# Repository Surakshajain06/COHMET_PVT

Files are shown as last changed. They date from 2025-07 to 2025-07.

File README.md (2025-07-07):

    

# **CMC COHMET**
## **Cognitive and Hand Motor Enhancement Trainer**

COHMET (Cognitive and Hand Motor Enhancement Trainer) is a smart, interactive pegboard designed to aid hand coordination and cognitive development—especially in stroke rehabilitation settings. It combines visual guidance through LED-lit wells, fixed-colored pegs, and real-time feedback to enhance user engagement. The system is Bluetooth-enabled, with app-based control for tracking progress, timing, and customizable audio prompts.

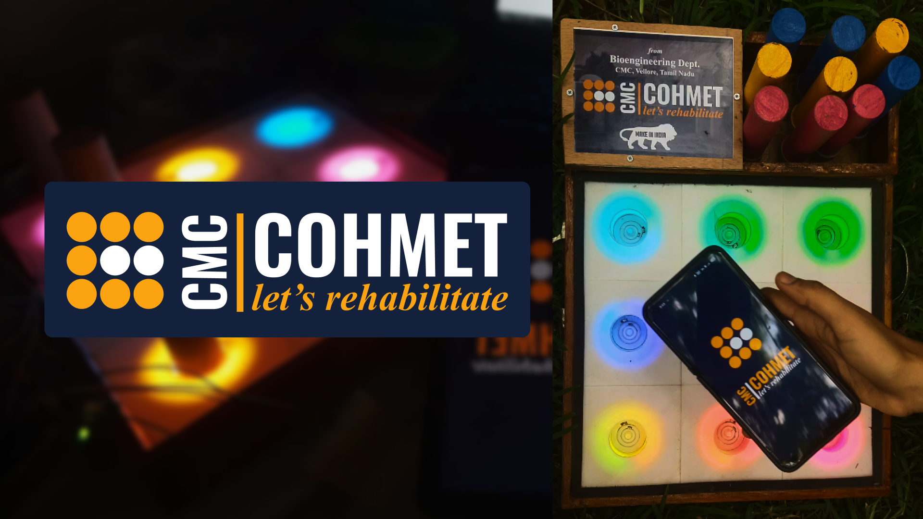
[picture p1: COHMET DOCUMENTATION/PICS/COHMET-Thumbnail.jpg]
Hero Image


## 🎯 **Functionality overview**
COHMET offers guided color-matching tasks that help improve motor skills and cognitive responses. Real-time peg placement detection ensures accurate activity tracking and user feedback. Designed with future expandability in mind, including data sync, remote monitoring, and multilingual support.

## 📱 **App integration and features**
A companion mobile app allows users or therapists to control sessions, monitor timing, and choose languages (English, Tamil, Hindi). Audio prompts, user tracking, and session customization are planned features under active development. COHMET is built to support scalable digital integration for remote therapy use.

## 📦 **Physical Design Overview**
COHMET features a compact wooden board with 9 wells and color-coded pegs, making it simple, durable, and user-friendly. Wells are illuminated for visual cues, and components are engineered for intuitive interaction. The system is lightweight and portable, suitable for clinics, therapy centers, or at-home use.

## ⚠️ Disclaimer
*COHMET is a prototype currently under development and intended for research and educational purposes only. Features, design, and performance are subject to change. The developers are not responsible for any misuse, damage, or injury resulting from the use of this system. Certain technical components and mechanisms are patent-pending and may not be reused or replicated without permission.*

## **ELECTRONICS STRUCTURE**
| Final Schematics | Final PCB |
| :---: | :---: |
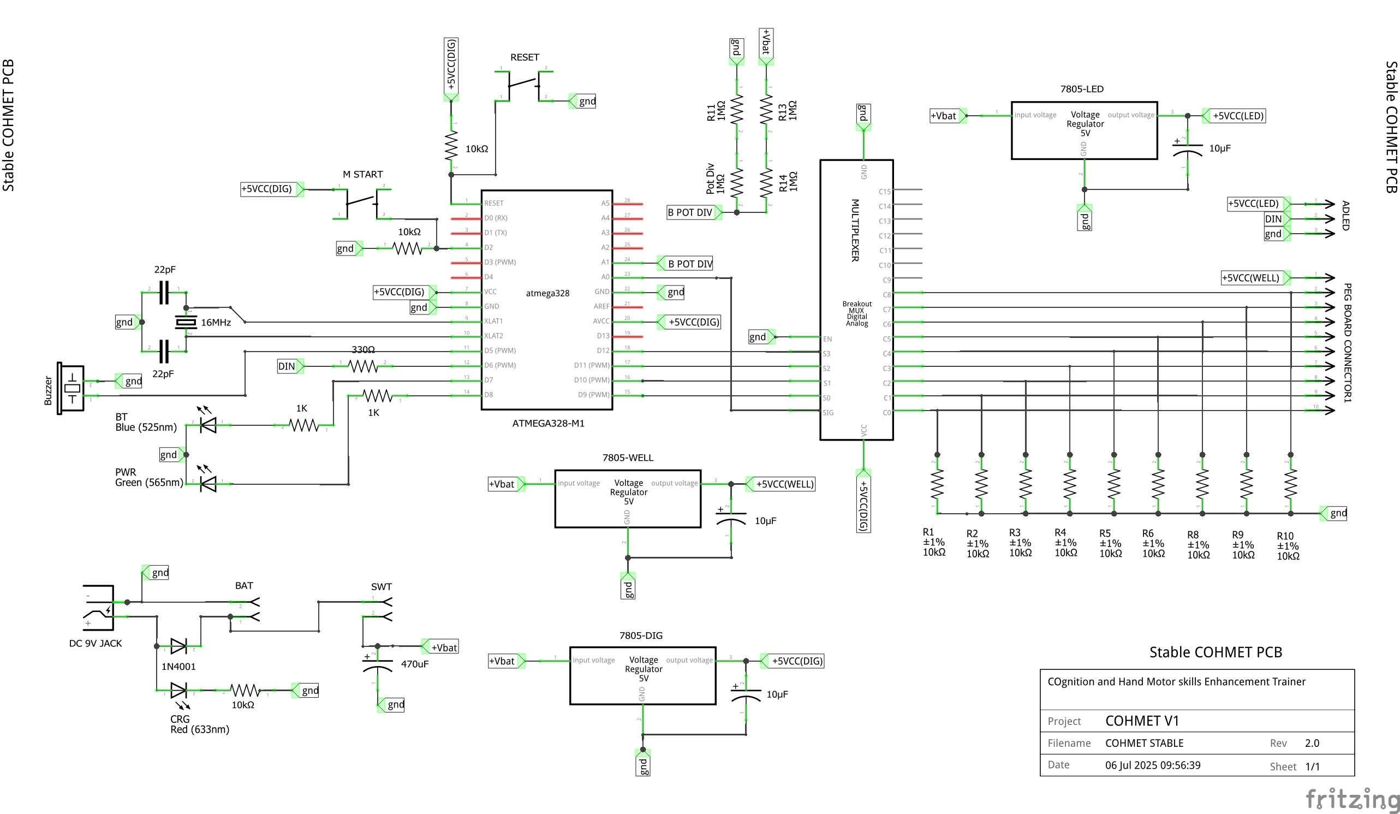
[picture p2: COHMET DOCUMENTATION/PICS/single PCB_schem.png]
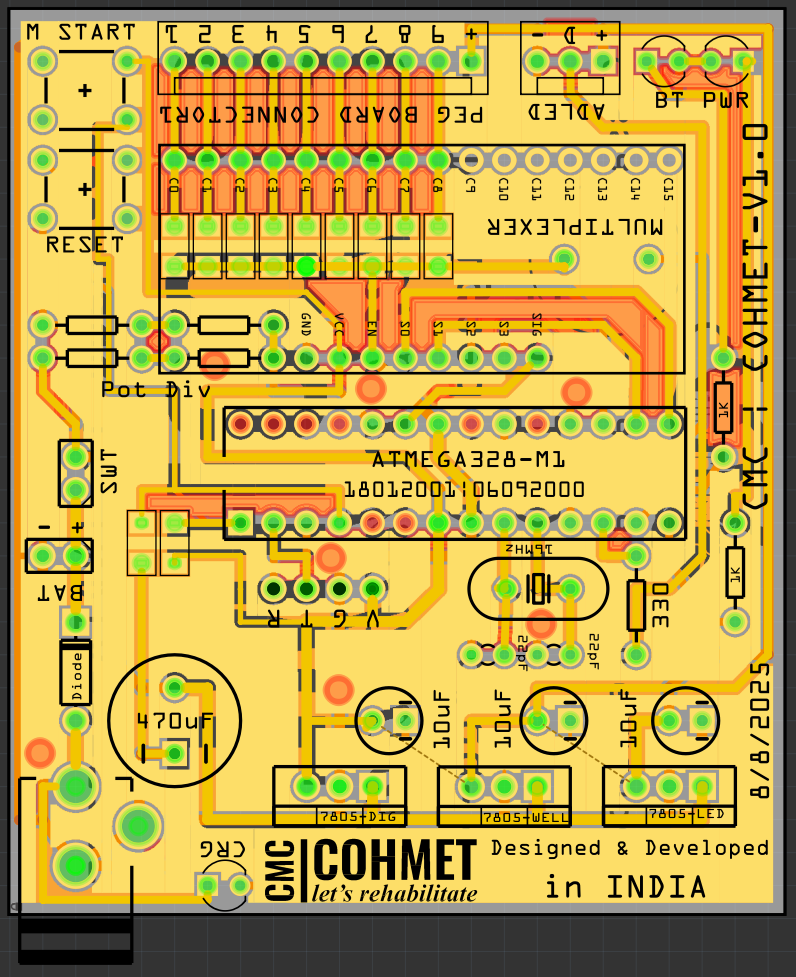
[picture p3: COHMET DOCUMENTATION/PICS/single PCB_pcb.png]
|  |  |

## **MECHANICAL STRUCTURE**
| Main Structures | Structural Assembly |
| :---: | :---: |
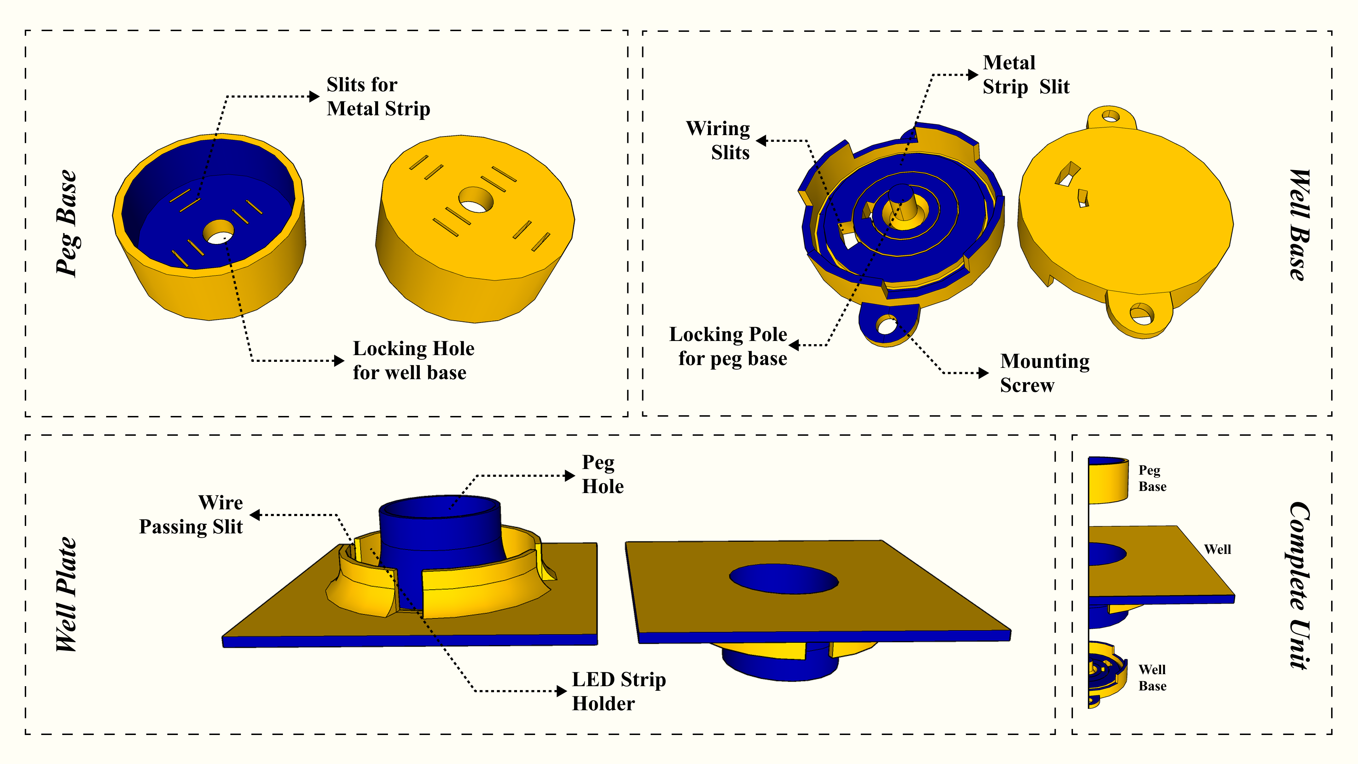
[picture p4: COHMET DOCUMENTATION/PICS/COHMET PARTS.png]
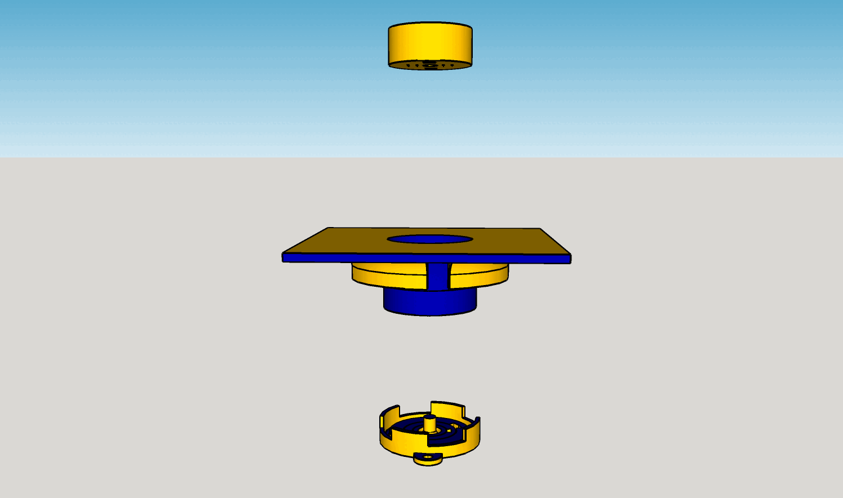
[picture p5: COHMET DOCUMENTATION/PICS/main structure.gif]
|  |  |

## **WEBSITE STRUCTURE**
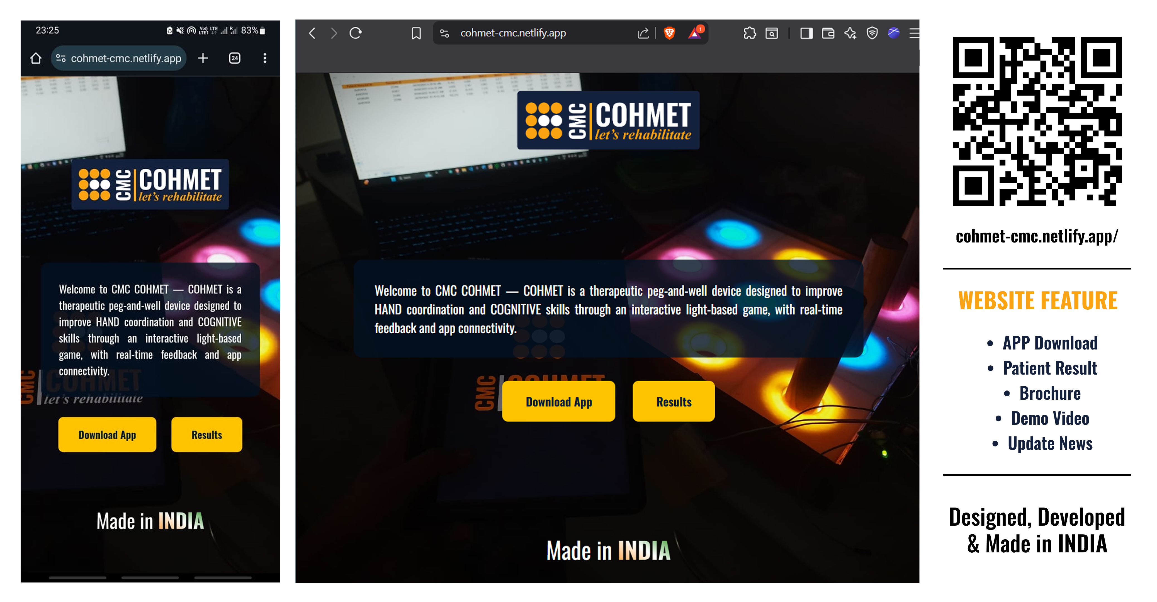
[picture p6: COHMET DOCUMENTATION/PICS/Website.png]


## **APP STRUCTURE**
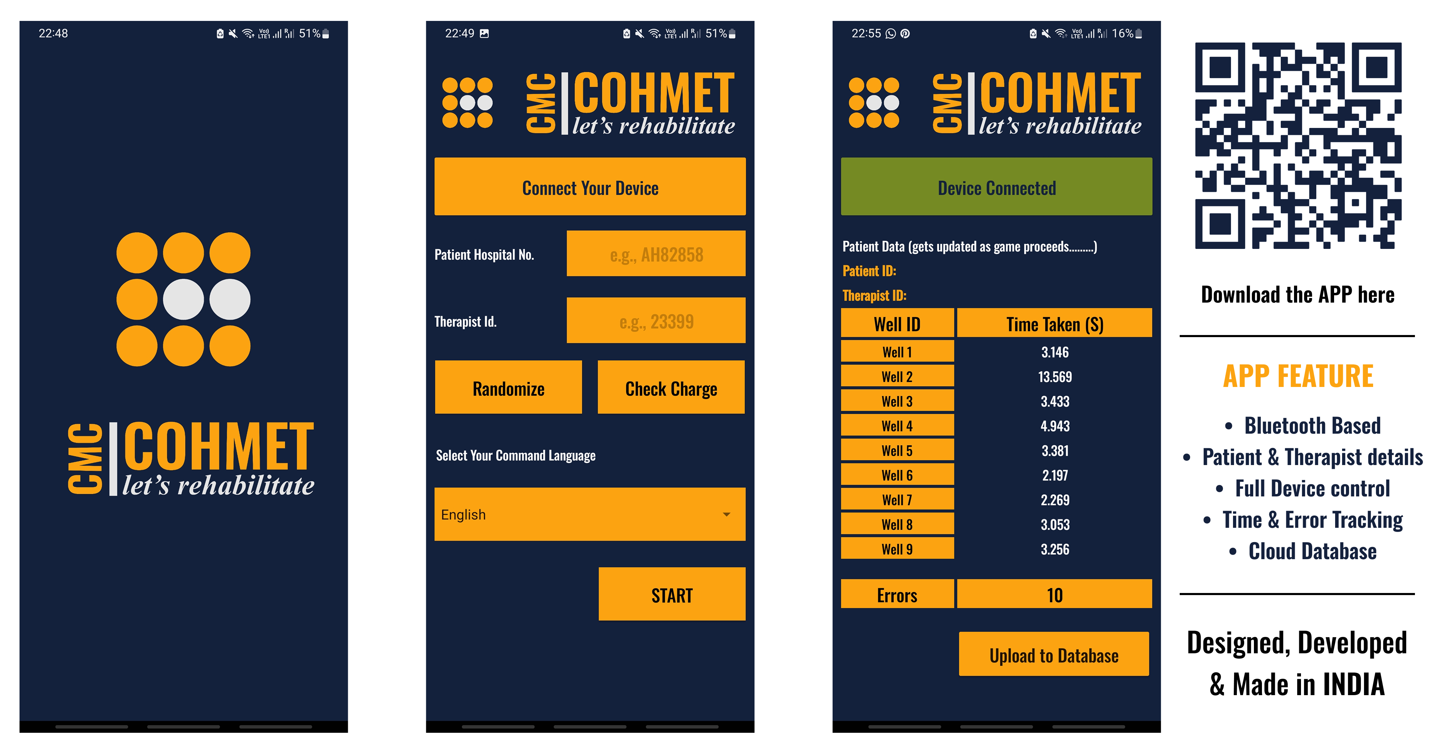
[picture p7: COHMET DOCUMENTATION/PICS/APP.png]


## 🔧 Future work
 
### 🔧 Proposed Improvements & Game Features

| **Category** | **Feature / Game Mode** | **Description** |
|---|---|---|
| ✅ **Hardware Optimization** | Minimize LED Voltage Regulator Heating | Improve power efficiency using low-dropout or switching regulators to reduce heat. |
| | Compact & Lightweight Design | Use smaller PCB, lighter enclosure, and optimized layout for portability. |
| | Cost Optimization | Use cost-effective components without reducing performance or safety. |
| 🔊 **Audio Functionality**  | Multilingual Audio Prompts (English, Tamil, Hindi) | Add voice instructions in three languages for accessibility. |
| | Custom Voice/Sound Support | Allow uploading custom audio files for personalized interaction. |
| ⏲️ **Training Flexibility** | Customizable Timer per Well | Set individual timing for each well to adapt training difficulty. |
| 🎮 **Game Modes** | **Memory Recall Game** | Flash a sequence of colors, and player replicates it using pegs. |
| | **Reaction Time Game** | Random fast-flashing wells; player responds quickly to correct one. |
| | **Color-Match Training (Current)** | Match colored peg with correct well; error shown with red flash. |
| | **Sequence Training Game** | Player must follow a specific color sequence given by audio or lights. |
| | **Timer Challenge Mode** | Complete all placements within a limited time. |
| | **Obstacle Mode** | Include false signals or distractions to improve focus and cognition. |
| | **Progressive Levels** | Increase difficulty with faster timing, more colors, and advanced logic. |
| 🧠 **Cognitive/Physical Goals** | Focus Training | Single-color attention game with distractions to improve sustained focus. |
| | Left-Right Alternation Game | Alternate peg placements to engage both hands and aid rehabilitation. |
| 📱 **User Control** | Mobile App-Based Control & Sync | Set modes and track results via Bluetooth-connected mobile app. |

## Behind the development



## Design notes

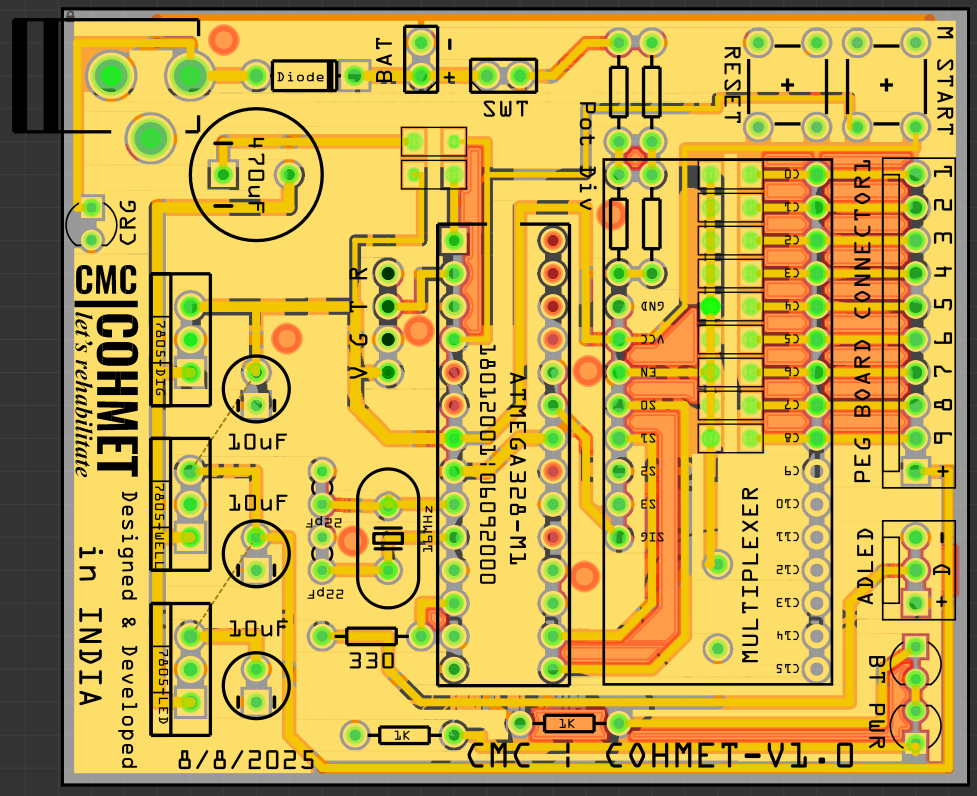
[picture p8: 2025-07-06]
COHMET ELECTRONICS/single PCB_pcb.png

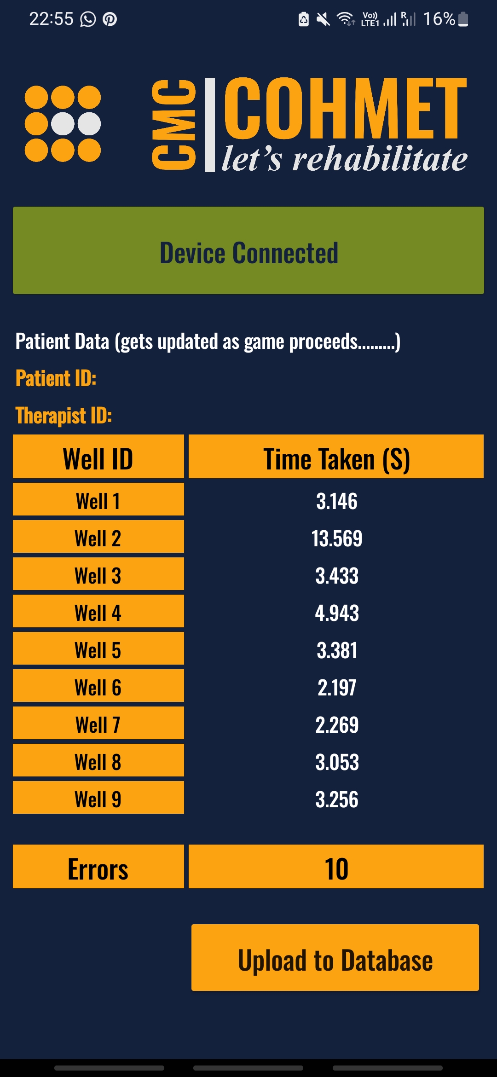
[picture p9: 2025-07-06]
COHMET DOCUMENTATION/PICS/APP4.jpg

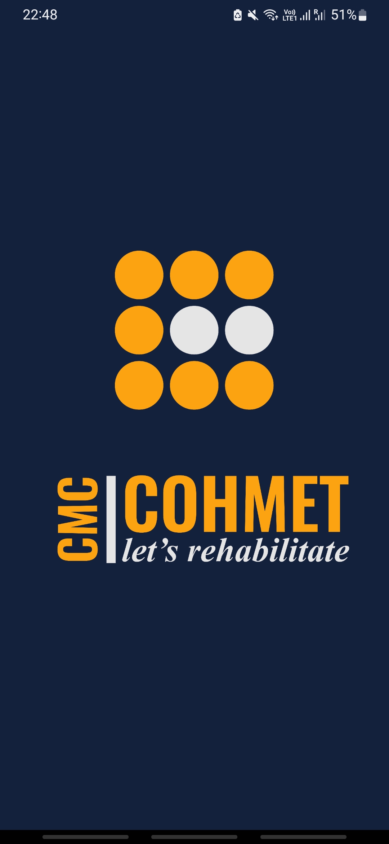
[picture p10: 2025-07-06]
COHMET DOCUMENTATION/PICS/APP1.jpg

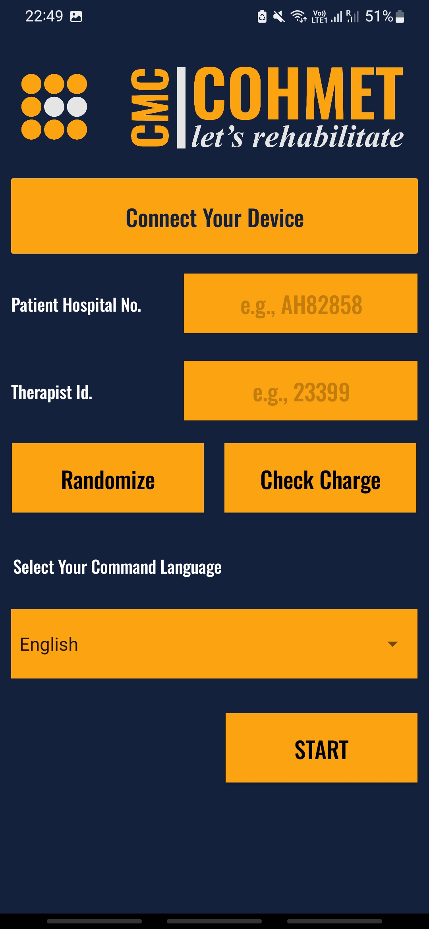
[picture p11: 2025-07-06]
COHMET DOCUMENTATION/PICS/APP2.jpg

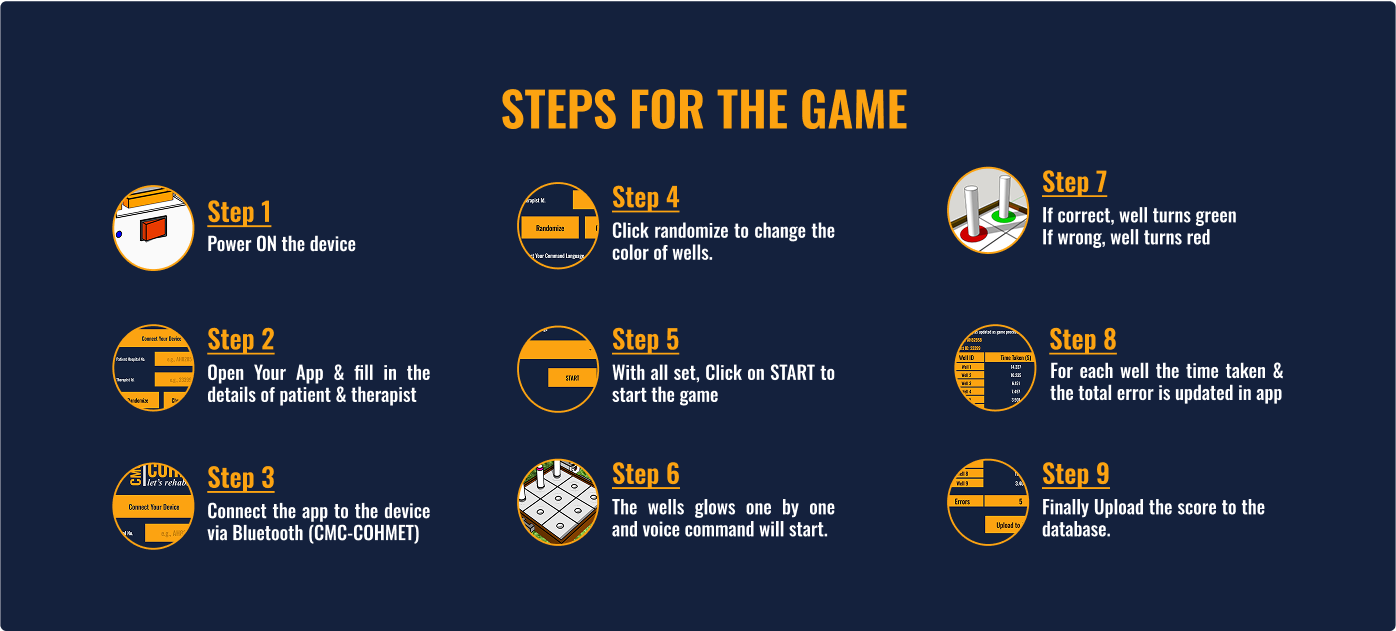
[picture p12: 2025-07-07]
COHMET WEBSITE/rules.png

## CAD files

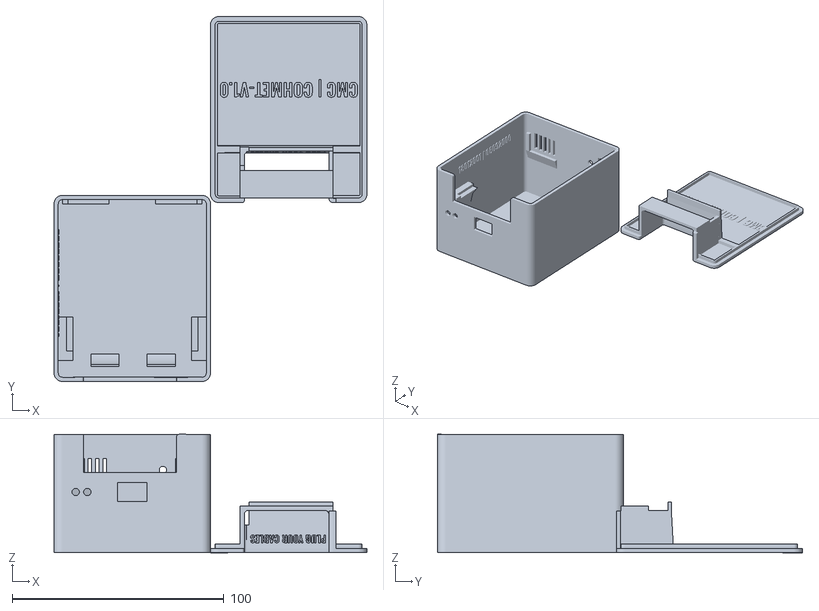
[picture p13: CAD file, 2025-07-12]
COHMET MECHNICAL/Prinatbles/ELECTRONICS CASE.stl
148.0 x 172.6 x 56.0

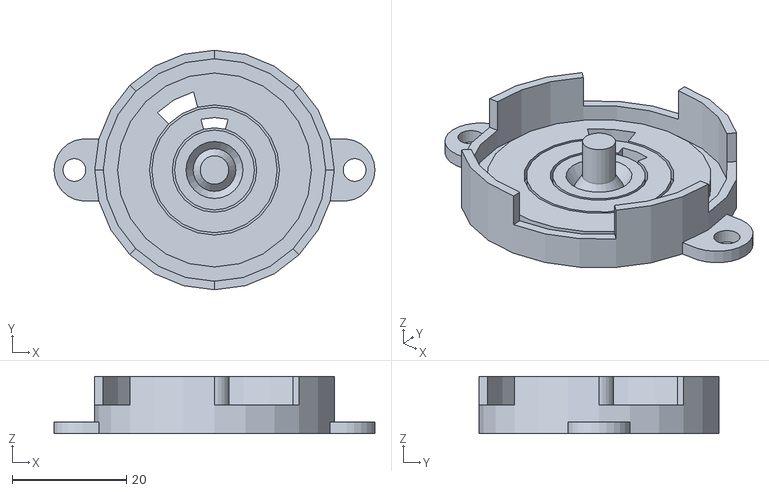
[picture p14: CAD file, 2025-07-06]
COHMET MECHNICAL/Prinatbles/Well Base.stl
56.3 x 42.0 x 10.0

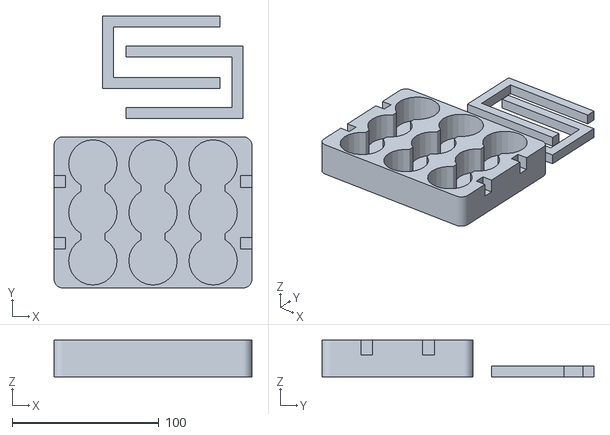
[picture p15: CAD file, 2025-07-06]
COHMET MECHNICAL/Prinatbles/Peg tray.stl
135.0 x 185.4 x 25.0

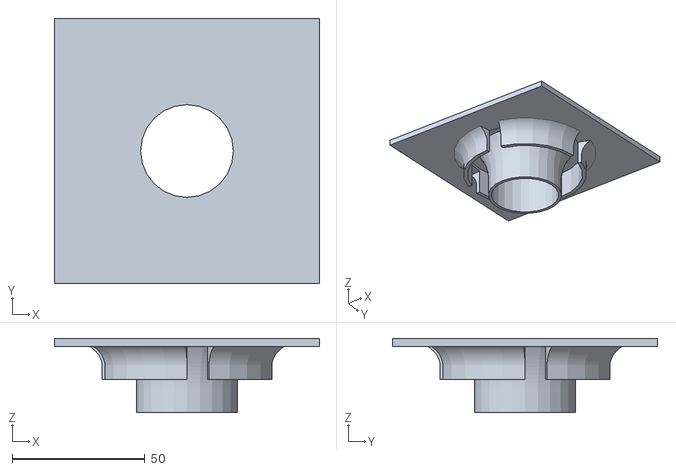
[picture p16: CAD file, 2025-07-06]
COHMET MECHNICAL/Prinatbles/Well.stl
100.0 x 100.0 x 28.0

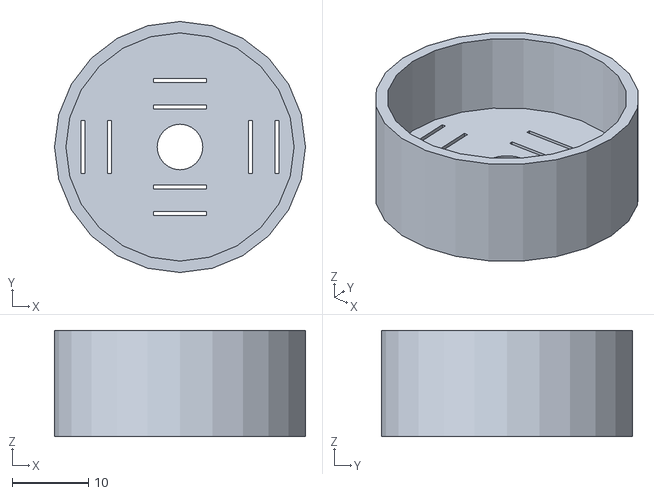
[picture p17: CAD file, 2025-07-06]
COHMET MECHNICAL/Prinatbles/Peg Base.stl
33.0 x 33.0 x 14.0

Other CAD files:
COHMET MECHNICAL/Main 3D File/Enclouser.skp
COHMET MECHNICAL/Main 3D File/Peg Base F.skp
COHMET MECHNICAL/Main 3D File/Peg tray.skp
COHMET MECHNICAL/Main 3D File/Well Base F.skp
COHMET MECHNICAL/Main 3D File/Well F.skp

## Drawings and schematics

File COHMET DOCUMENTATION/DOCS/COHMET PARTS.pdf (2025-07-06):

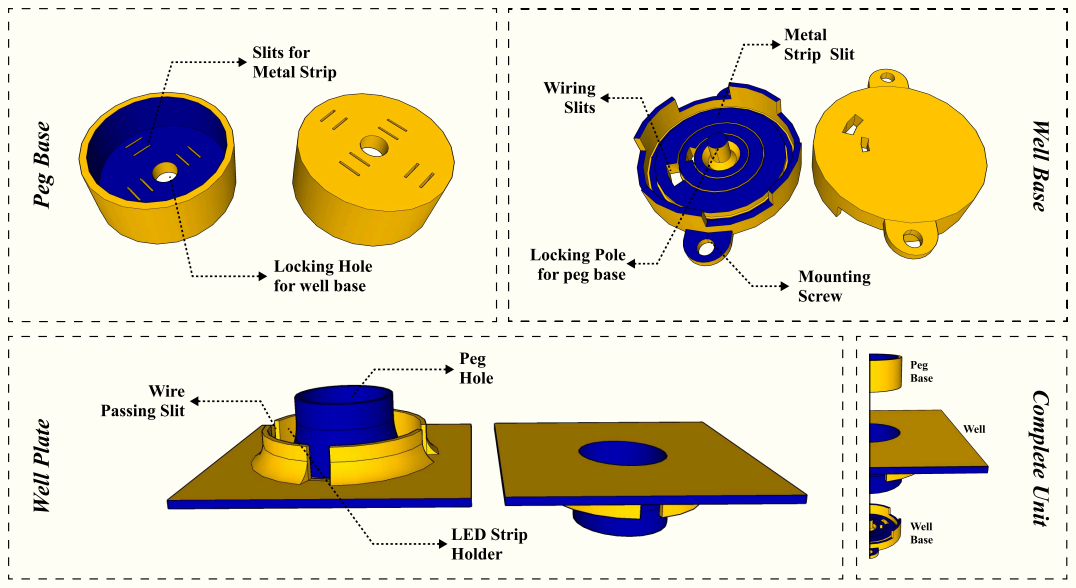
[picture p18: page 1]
Well Base; Locking Pole; for peg base; Mounting; Screw; Metal; Strip Slit; Wiring; Slits; Peg Base; Slits for; Metal Strip; Well Plate; Peg; Hole; Wire; Passing Slit; LED Strip; Holder; Complete Unit; Base; Well

Locking Hole
for well base

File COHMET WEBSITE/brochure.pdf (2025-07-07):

# COHMET

8

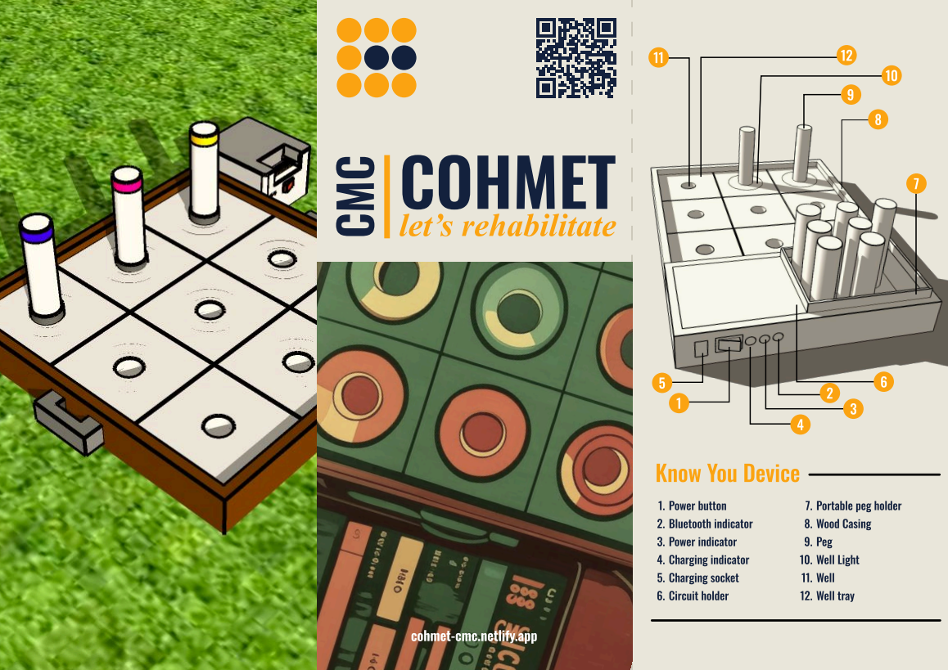
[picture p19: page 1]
CMC; let’s rehabilitate; /# Power butto'; # Bluetooth indicato!; # Power indicato!; .# Charging indicato!; # Charging socke); # Circuit holder; 9# Wood Casin@; B# Peg<; /1# Well Ligh); //# Wel:; /# Well tray

Know You Device

O# Portable peg holde!

cohmet-cmc.netlify.app

# Step 1

# Step 2

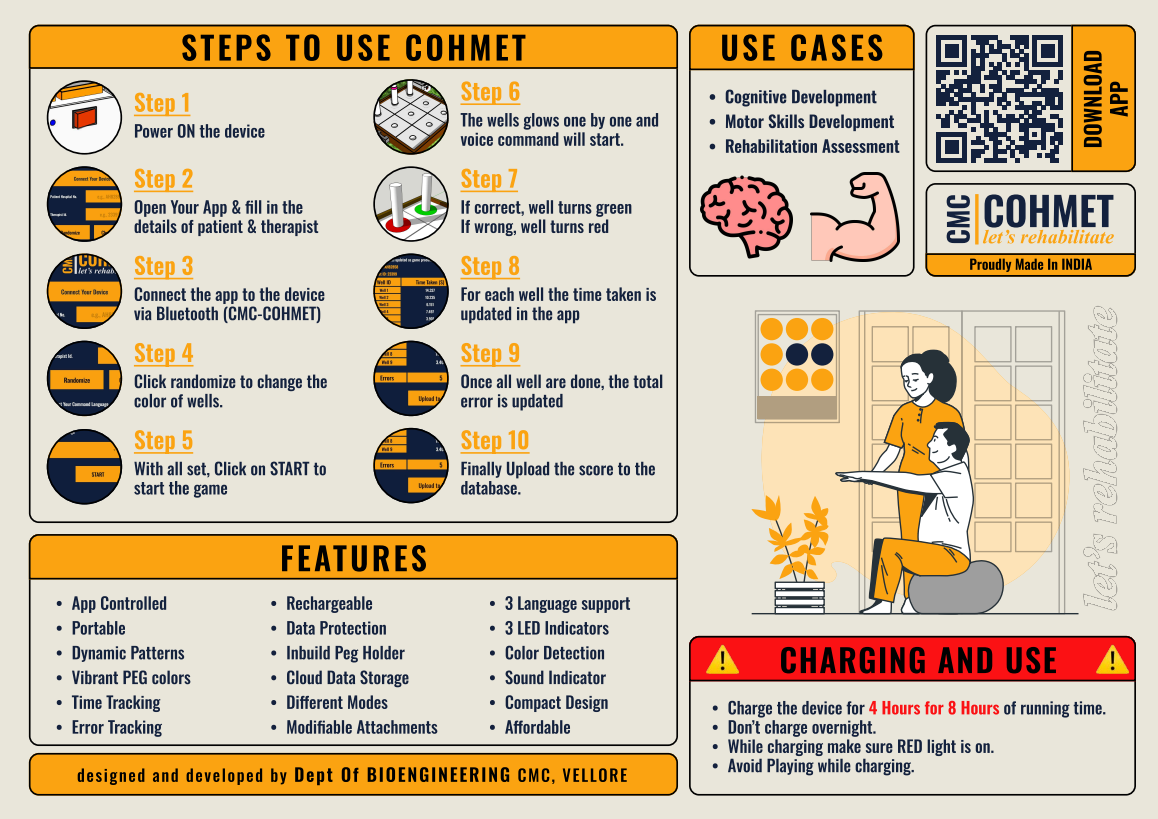
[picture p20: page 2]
Step 4; Step 6; Charge the device for; of running time; App Controlle8; PortableA; Dynamic Pattern4; Vibrant PEG color4; Time Trackin*; Error Tracking; RechargeableA; Different Mode4; Modifiable Attachments; 3 Language supporx; 3 LED Indicator4; Color DetectioQ; Sound Indicato[; Compact DesigQ; Affordable; FEATURES; USE CASES; DOWNLOAD; APP; rehabilitate; COHMET; CMC; let’s rehabilitate

STEPS TO USE COHMET

 Cognitive Developmen
 Motor Skills Developmen
 Rehabilitation Assessment

The wells glows one by one and
voice command will start.
Step 7

Power ON the device

Open Your App & fill in the
details of patient & therapist
Step 3

If correct, well turns green
If wrong, well turns red
Step 8

Proudly Made In INDIA

Connect the app to the device
via Bluetooth (CMC-COHMET)

For each well the time taken is
updated in the app
Step 9

Click randomize to change the
color of wells.
Step 5

Once all well are done, the total
error is updated
Step 10

With all set, Click on START to
start the game

Finally Upload the score to the
database.

️CHARGING AND USE let’s

Data ProtectioQ
Inbuild Peg Holde[
Cloud Data Storag^

Don t charge overnight
While charging make sure RED light is on
Avoid Playing while charging.

4 Hours for 8 Hours

designed and developed by Dept Of BIOENGINEERING CMC, VELLORE

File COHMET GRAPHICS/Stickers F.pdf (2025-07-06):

# STEPS FOR THE GAME

## Step 1

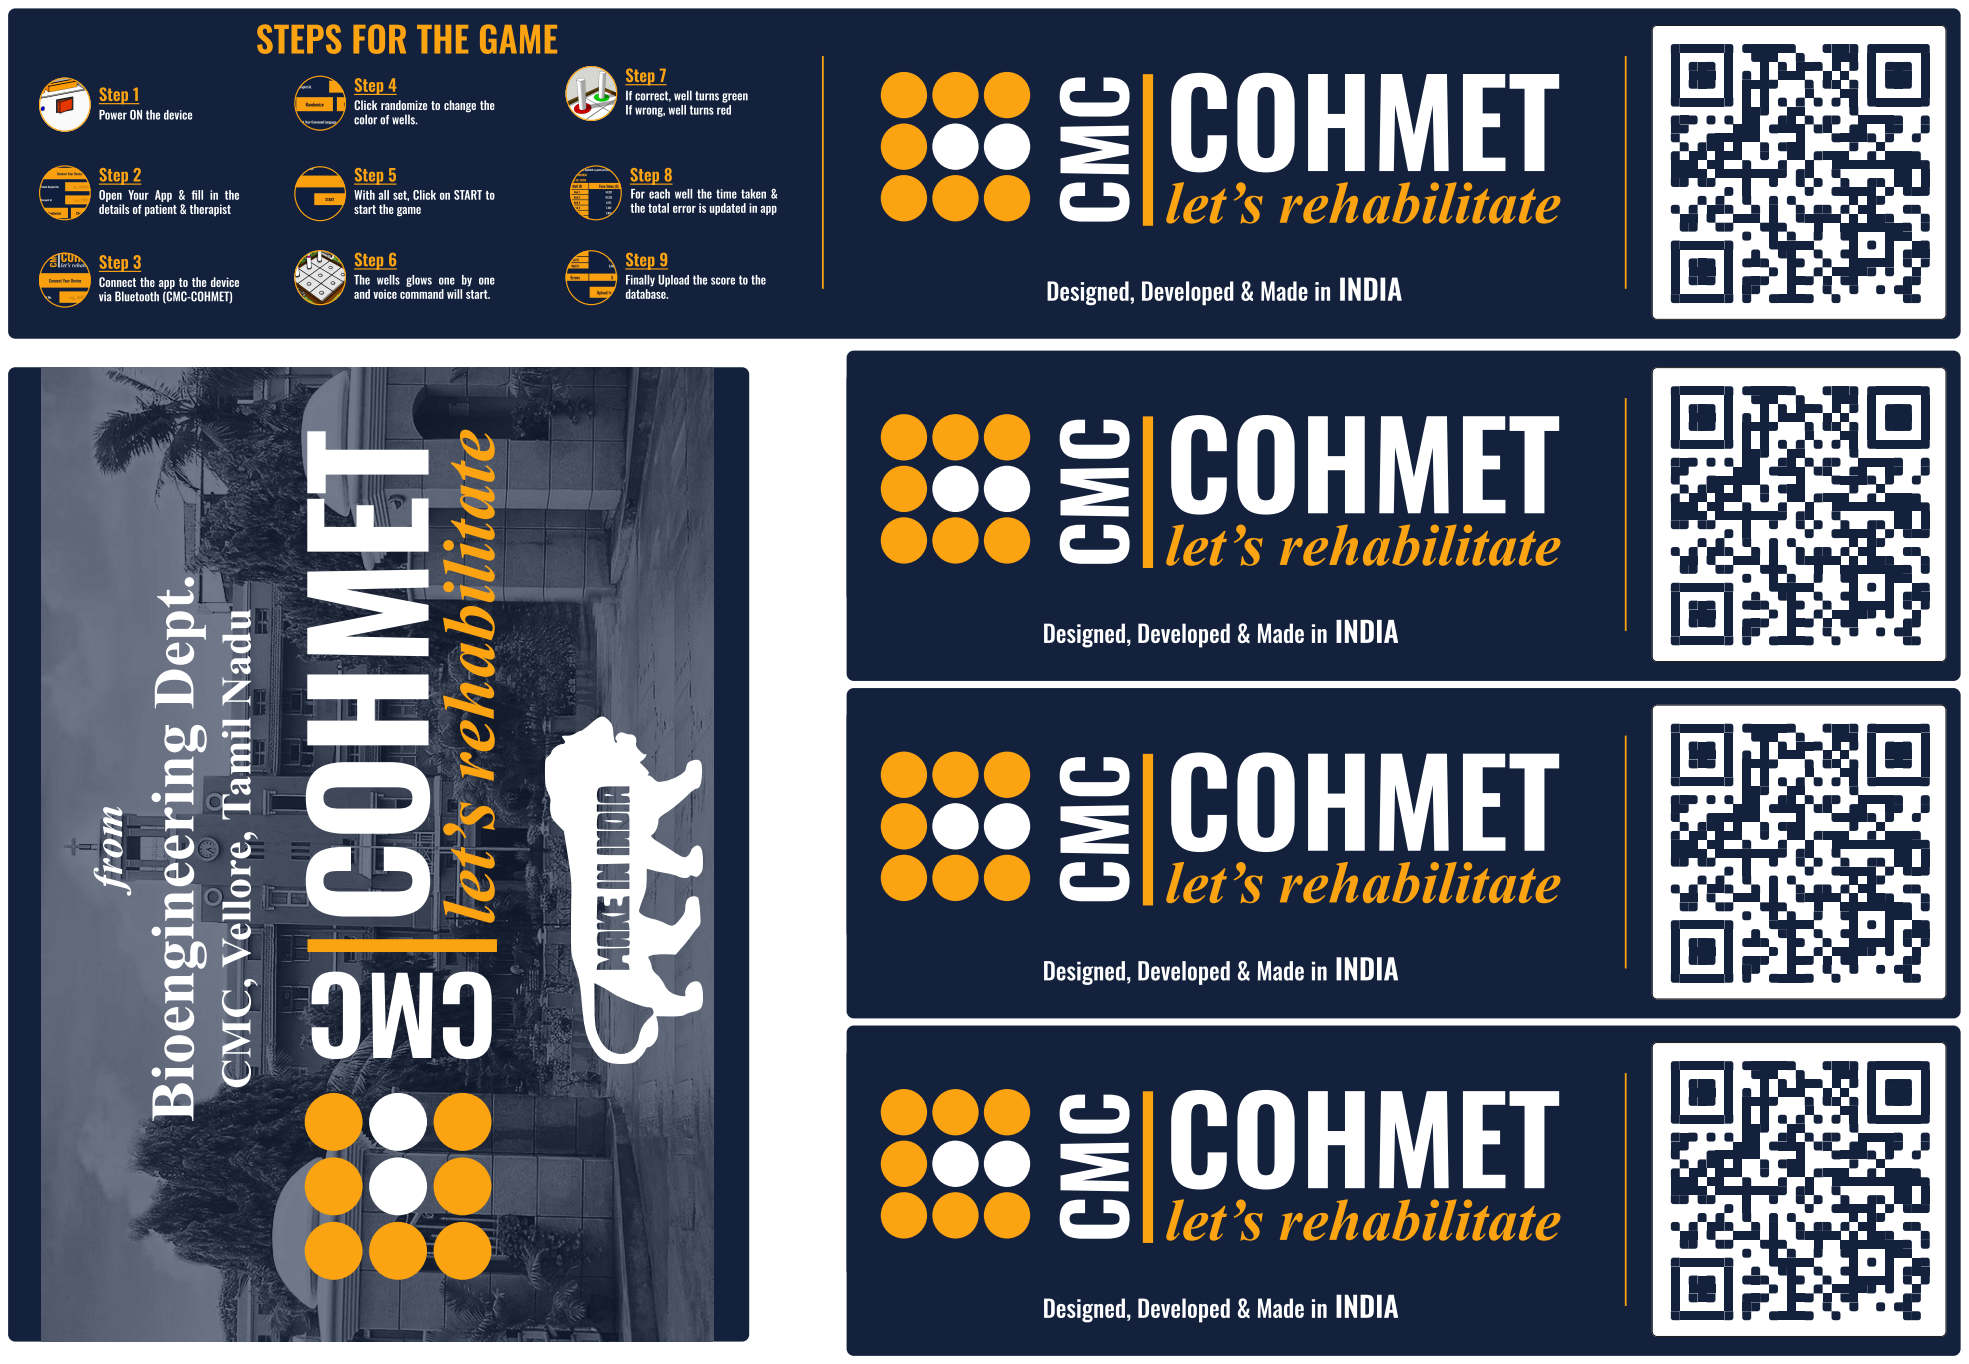
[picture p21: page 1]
Step 2; Step 5; Step 3; Step 4; Step 6; Step 7; Step 8; Step 9; COHMET; CMC; let’s; rehabilitate; INDI; from; Bioengineering Dept.; let’s rehabilitate; A COHMET

If correct, well turns green
If wrong, well turns red

Power ON the device

Click randomize to change the
color of wells.

Open Your App & fill in the
details of patient & therapist

With all set, Click on START to
start the game

For each well the time taken &
the total error is updated in app

Connect the app to the device
via Bluetooth (CMC-COHMET)

The wells glows one by one
and voice command will start.

Finally Upload the score to the
database.

Designed, Developed & Made in

CMC, Vellore, Tamil Nadu

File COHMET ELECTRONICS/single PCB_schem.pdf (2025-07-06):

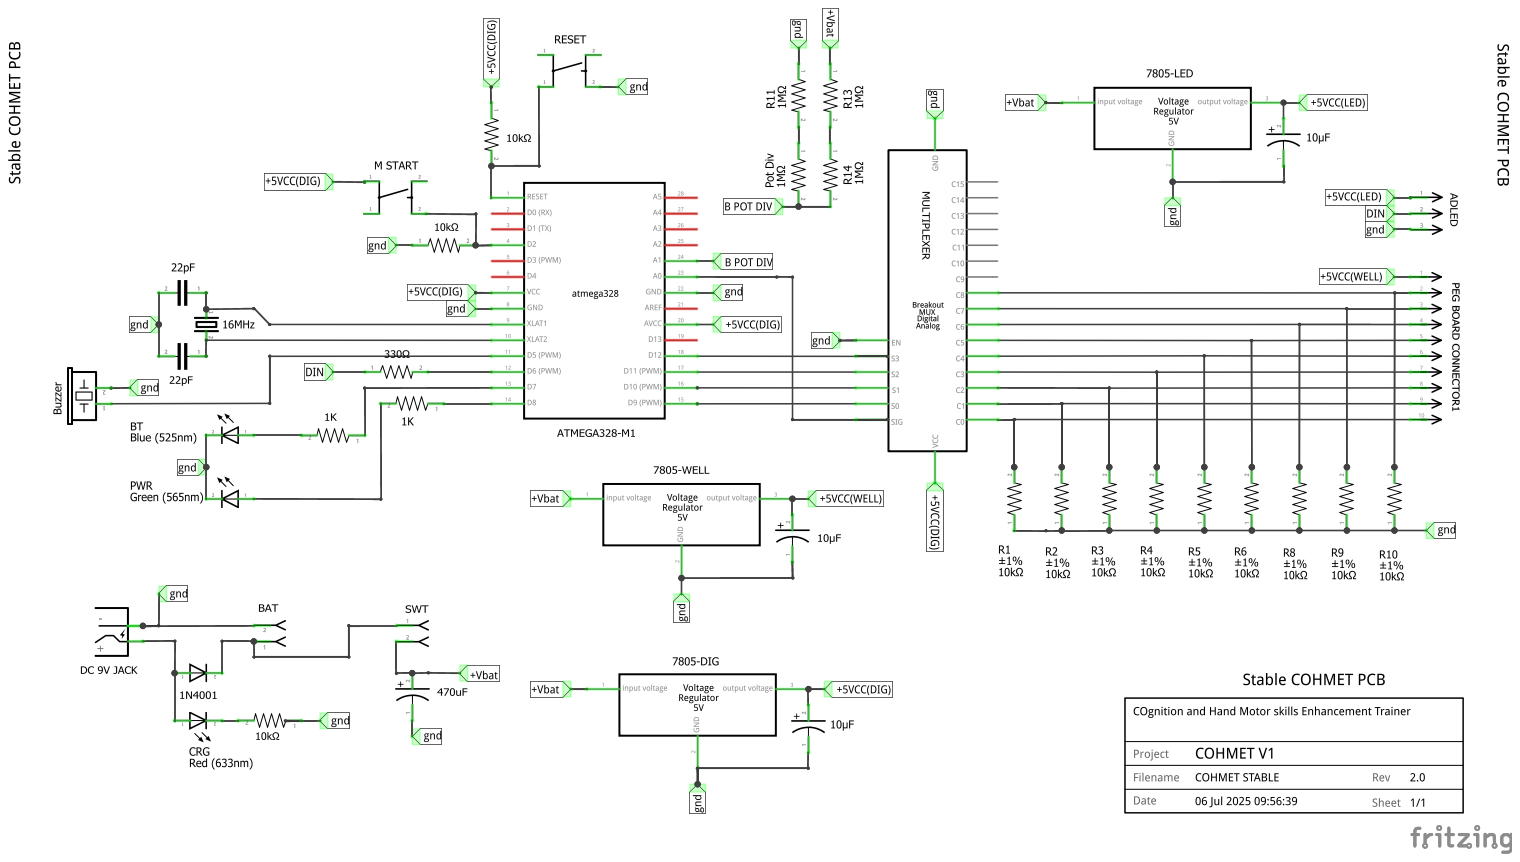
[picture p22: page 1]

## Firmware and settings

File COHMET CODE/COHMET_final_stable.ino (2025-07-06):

#include <Adafruit_NeoPixel.h>
#include <SoftwareSerial.h>

// ---------------------- Pin Definitions ----------------------
#define RX_PIN 0
#define TX_PIN 1
#define MANUAL_START_PIN 3
#define BUZZER_PIN 5
#define LED_PIN 6
#define BT_LED 7
#define POWER_INDICATOR 8
#define MUX_S0 9
#define MUX_S1 10
#define MUX_S2 11
#define MUX_S3 12
#define MUX_SIGNAL A0
#define BATTERY_READ A1

// ---------------------- Game Config ----------------------
#define NUM_WELLS 9
#define LEDS_PER_WELL 10
#define NUM_LEDS (NUM_WELLS * LEDS_PER_WELL)
#define COLOR_PINK   0
#define COLOR_BLUE   1
#define COLOR_YELLOW 2
#define COLOR_GREEN  3
#define COLOR_OFF    4

const int PINK_MIN = 300, PINK_MAX = 380;
const int BLUE_MIN = 470, BLUE_MAX = 550;
const int YELLOW_MIN = 640, YELLOW_MAX = 730;

uint8_t colorMap[3][3] = {
  {250, 50, 150},   // Pink
  {0, 70, 255},     // Blue
  {255, 128, 0}     // Yellow
};

// ---------------------- State Variables ----------------------
Adafruit_NeoPixel strip(NUM_LEDS, LED_PIN, NEO_GRB + NEO_KHZ800);
SoftwareSerial BT(RX_PIN, TX_PIN);

uint8_t wellColors[NUM_WELLS];
bool matchedWells[NUM_WELLS];
unsigned long wellTimes[NUM_WELLS];

bool gameRunning = false;
bool sequenceAssigned = false;

uint8_t currentWell = 0;
uint8_t errorCount = 0;
unsigned long wellStartTime;

unsigned long lastFlashTime = 0;
bool flashOn = false;
const unsigned long flashInterval = 300;

// ---------------------- Helper Functions ----------------------
void setMuxChannel(uint8_t ch) {
  digitalWrite(MUX_S0, ch & 0x01);
  digitalWrite(MUX_S1, (ch >> 1) & 0x01);
  digitalWrite(MUX_S2, (ch >> 2) & 0x01);
  digitalWrite(MUX_S3, (ch >> 3) & 0x01);
}

void setWellColor(uint8_t well, uint8_t colorId) {
  uint8_t r = 0, g = 0, b = 0;
  if (colorId <= COLOR_YELLOW) {
    r = colorMap[colorId][0];
    g = colorMap[colorId][1];
    b = colorMap[colorId][2];
  } else if (colorId == COLOR_GREEN) {
    r = 0; g = 255; b = 0;
  } else {
    r = g = b = 0;
  }

  for (uint8_t i = 0; i < LEDS_PER_WELL; i++) {
    strip.setPixelColor(well * LEDS_PER_WELL + i, strip.Color(r, g, b));
  }
}

void clearAllWells() {
  for (uint8_t i = 0; i < NUM_WELLS; i++) {
    setWellColor(i, COLOR_OFF);
  }
  strip.show();
}

uint8_t readPegColor(uint16_t adcValue) {
  if (adcValue >= PINK_MIN && adcValue <= PINK_MAX) return COLOR_PINK;
  if (adcValue >= BLUE_MIN && adcValue <= BLUE_MAX) return COLOR_BLUE;
  if (adcValue >= YELLOW_MIN && adcValue <= YELLOW_MAX) return COLOR_YELLOW;
  return 255;
}

void checkCurrentWell() {
  setMuxChannel(currentWell);
  delay(10);
  int adcVal = analogRead(MUX_SIGNAL);
  uint8_t pegColor = readPegColor(adcVal);

  if (pegColor == wellColors[currentWell]) {
    setWellColor(currentWell, COLOR_GREEN);
    strip.show();
    matchedWells[currentWell] = true;
    wellTimes[currentWell] = millis() - wellStartTime;

    BT.print("TIME:");
    BT.println(wellTimes[currentWell]);

    currentWell++;
    if (currentWell < NUM_WELLS) {
      wellStartTime = millis();
    } else {
      BT.print("TIME:");
      BT.println(errorCount);
      gameRunning = false;
      showCompletionAnimation();
      sequenceAssigned = false;
    }
  } else if (pegColor != 255) {
    errorCount++;

    for (int i = 0; i < 3; i++) {
      for (uint8_t j = 0; j < LEDS_PER_WELL; j++) {
        strip.setPixelColor(currentWell * LEDS_PER_WELL + j, strip.Color(255, 0, 0));
      }
      strip.show();
      tone(BUZZER_PIN, 1000, 100);
      delay(150);

      for (uint8_t j = 0; j < LEDS_PER_WELL; j++) {
        strip.setPixelColor(currentWell * LEDS_PER_WELL + j, strip.Color(0, 0, 0));
      }
      strip.show();
      delay(150);
    }

    uint8_t col = wellColors[currentWell];
    for (uint8_t j = 0; j < LEDS_PER_WELL; j++) {
      strip.setPixelColor(currentWell * LEDS_PER_WELL + j,
        strip.Color(colorMap[col][0], colorMap[col][1], colorMap[col][2]));
    }
    strip.show();
  }
}

void updateWellDisplay() {
  for (uint8_t i = 0; i < NUM_WELLS; i++) {
    if (matchedWells[i]) setWellColor(i, COLOR_GREEN);
    else if (i == currentWell && flashOn) setWellColor(i, wellColors[i]);
    else setWellColor(i, COLOR_OFF);
  }
  strip.show();
}

void showCompletionAnimation() {
  for (int k = 0; k < 3; k++) {
    for (uint8_t i = 0; i < NUM_WELLS; i++) setWellColor(i, COLOR_GREEN);
    strip.show(); delay(300);
    clearAllWells(); delay(300);
  }

  for (int frame = 0; frame < 50; frame++) {
    for (uint8_t w = 0; w < NUM_WELLS; w++) {
      for (uint8_t l = 0; l < LEDS_PER_WELL; l++) {
        uint16_t hue = (frame * 500 + w * 3000 + l * 400) % 65536;
        strip.setPixelColor(w * LEDS_PER_WELL + l, strip.gamma32(strip.ColorHSV(hue)));
      }
    }
    strip.show();
    delay(50);
  }

  // Ending tone sequence
  tone(BUZZER_PIN, 800, 150); delay(200);
  tone(BUZZER_PIN, 1200, 150); delay(200);
  tone(BUZZER_PIN, 1600, 250); delay(300);

  clearAllWells();
}

void randomizeColors() {
  uint8_t pos[NUM_WELLS] = {0,1,2,3,4,5,6,7,8};
  for (uint8_t i = 0; i < NUM_WELLS; i++) {
    uint8_t j = random(i, NUM_WELLS);
    uint8_t t = pos[i]; pos[i] = pos[j]; pos[j] = t;
  }

  for (uint8_t i = 0; i < NUM_WELLS; i++) {
    if (i < 3) wellColors[pos[i]] = COLOR_PINK;
    else if (i < 6) wellColors[pos[i]] = COLOR_BLUE;
    else wellColors[pos[i]] = COLOR_YELLOW;
  }

  sequenceAssigned = true;
  clearAllWells();
  tone(BUZZER_PIN, 1500, 100);
  delay(150);
}

void checkBattery() {
  int adcVal = analogRead(BATTERY_READ);
  float voltage = adcVal * (5.0 / 1023.0) * 2.0; // voltage divider assumed
  float percent = ((voltage - 5.8) / (6.4 - 5.8)) * 100.0;
  percent = constrain(percent, 0, 100);
  BT.println((int)percent);
}


// ---------------------- Setup ----------------------
void setup() {
  pinMode(MANUAL_START_PIN, INPUT);
  pinMode(BUZZER_PIN, OUTPUT);
  pinMode(BT_LED, OUTPUT);
  pinMode(POWER_INDICATOR, OUTPUT);
  pinMode(MUX_S0, OUTPUT);
  pinMode(MUX_S1, OUTPUT);
  pinMode(MUX_S2, OUTPUT);
  pinMode(MUX_S3, OUTPUT);

  digitalWrite(POWER_INDICATOR, HIGH);
  digitalWrite(BT_LED, LOW);

  strip.begin();
  strip.show();
  randomSeed(analogRead(0));
  BT.begin(9600);

  // Startup tone
  tone(BUZZER_PIN, 600, 100); delay(150);
  tone(BUZZER_PIN, 1000, 100); delay(150);
  tone(BUZZER_PIN, 1400, 150); delay(200);

  // RGB color blending animation
  for (int j = 0; j < 256; j++) {
    for (int i = 0; i < NUM_LEDS; i++) {
      uint16_t hue = (i * 700 + j * 256) % 65536;
      strip.setPixelColor(i, strip.gamma32(strip.ColorHSV(hue)));
    }
    strip.show();
    delay(15);
  }

  clearAllWells();
}

// ---------------------- Loop ----------------------
void loop() {
  if (BT.available()) {
    uint8_t cmd = BT.read();
    digitalWrite(BT_LED, HIGH); delay(100); digitalWrite(BT_LED, LOW);

    if (cmd == 1) {
      randomizeColors();
    } else if (cmd == 6 && sequenceAssigned) {
      gameRunning = true;
      currentWell = 0;
      errorCount = 0;
      for (int i = 0; i < NUM_WELLS; i++) matchedWells[i] = false;
      clearAllWells();
      wellStartTime = millis();
      lastFlashTime = millis();
      flashOn = false;
    } else if (cmd == 2) {
      checkBattery();
    }
  }

  if (gameRunning) {
    if (millis() - lastFlashTime > flashInterval) {
      flashOn = !flashOn;
      lastFlashTime = millis();
      updateWellDisplay();
    }
    checkCurrentWell();
  } else if (!gameRunning && sequenceAssigned) {
    for (uint8_t i = 0; i < NUM_WELLS; i++) setWellColor(i, wellColors[i]);
    strip.show();
    delay(100);
  } else {
    for (uint8_t i = 0; i < NUM_LEDS; i++) {
      uint16_t hue = (millis() * 10 + i * 100) % 65536;
      strip.setPixelColor(i, strip.gamma32(strip.ColorHSV(hue)));
    }
    strip.show();
    delay(30);
  }

  if (digitalRead(MANUAL_START_PIN)) {
    randomizeColors();
    delay(200);
    tone(BUZZER_PIN, 2000, 200);
    delay(500);
    gameRunning = true;
    currentWell = 0;
    errorCount = 0;
    for (int i = 0; i < NUM_WELLS; i++) matchedWells[i] = false;
    clearAllWells();
    wellStartTime = millis();
  }
}

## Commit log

2025-07-06 Initial commit with all project files
    [Peg Base F.skp, Peg Base.stl, Peg tray.skp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]
2025-07-12 logo updates
    [ELECTRONICS CASE.stl, Enclouser.skp]
